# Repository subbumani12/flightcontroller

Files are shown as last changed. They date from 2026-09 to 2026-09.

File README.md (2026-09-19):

# Flight Controller

A custom **STM32F411-based flight controller PCB** designed for multirotor, UAV, robotics, and embedded flight-control applications.

The board integrates an IMU, magnetometer, barometric sensor, EEPROM, MicroSD storage, USB-C, SWD debugging, UART interfaces, and dedicated motor/auxiliary outputs on a compact **2-layer PCB** designed in KiCad.

## 3D Render
<p align="center">
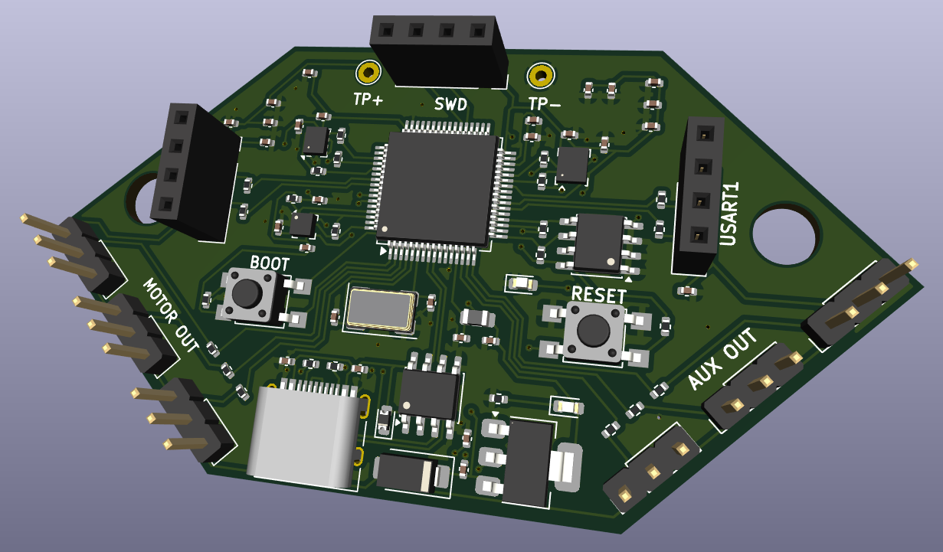
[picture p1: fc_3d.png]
STM32 Flight Controller 3D Render
  
</p>

---

## ✈️ Overview

This project is a custom flight-controller hardware design centered around the **STM32F411RET6 ARM Cortex-M4** microcontroller.

The STM32 handles sensor acquisition, flight-control processing, peripheral communication, data logging, and motor/auxiliary output generation.

The board combines:

* Inertial sensing
* Magnetic heading measurement
* Barometric altitude measurement
* Non-volatile configuration storage
* Flight-data logging
* USB communication
* SWD programming/debugging
* Motor and auxiliary outputs
* UART communication

The PCB was designed in **KiCad**, with emphasis on compact routing, sensor decoupling, accessible debugging, and organized external interfaces.

---

## 🔧 Hardware Features

| Component | Part |
| --- | --- |
| **Microcontroller** | STM32F411RET6 |
| **IMU** | LSM6DS3 – 3-axis Accelerometer + 3-axis Gyroscope |
| **Magnetometer** | LIS3MDL – 3-axis |
| **Barometer** | BMP280 |
| **EEPROM** | AT24C256A |
| **Storage** | MicroSD |
| **USB** | USB Type-C |
| **Debug** | SWD |
| **Serial** | UART1 / UART2 |
| **Motor Outputs** | MOTOR1 / MOTOR2 / MOTOR3 |
| **Auxiliary Outputs** | AUX1 / AUX2 / AUX3 |
| **Logic Supply** | 3.3 V |
| **PCB** | 2-layer |
| **EDA Tool** | KiCad |

The complete hardware feature set is documented in the original design specification.

---

## 🧠 System Architecture

```text
                         USB Type-C
                             │
                             ▼
                       USB Protection
                             │
                             ▼
                       Power / 3.3 V
                             │
                             ▼
                    ┌─────────────────┐
                    │   STM32F411     │
                    │   Flight MCU    │
                    └────────┬────────┘
                             │
          ┌──────────────────┼──────────────────┐
          │                  │                  │
          ▼                  ▼                  ▼
        I²C                 SPI               UART
          │                  │                  │
    ┌─────┼─────┐       ┌────┴────┐       ┌────┴────┐
    ▼     ▼     ▼       ▼         ▼       ▼         ▼
  LSM6DS3 LIS3MDL EEPROM BMP280   MicroSD  UART1    UART2
    │     │
    └─────┴────── Sensor Data
                    │
                    ▼
              STM32 Processing
                    │
             ┌──────┴──────┐
             ▼             ▼
        Motor Outputs   AUX Outputs
             │
             ▼
            ESCs
```

---

## 📡 Sensors & Peripherals

### LSM6DS3 IMU

The **LSM6DS3** provides:

* 3-axis accelerometer
* 3-axis gyroscope

It serves as the primary inertial sensor for attitude estimation, angular-rate measurement, motion detection, and flight-control feedback.

The IMU communicates with the STM32 through **I²C**.

### LIS3MDL Magnetometer

The **LIS3MDL** provides 3-axis magnetic-field measurements and can be used as a magnetic heading reference for navigation and orientation estimation.

It communicates through **I²C** and includes an interrupt connection to the MCU.

### BMP280 Barometer

The **BMP280** provides pressure measurements for:

* Relative altitude estimation
* Altitude-hold applications
* Vertical-motion estimation
* Flight-data logging

The sensor is connected through **SPI**.

### AT24C256A EEPROM

The onboard EEPROM provides non-volatile storage for:

* Configuration parameters
* Calibration data
* Controller settings
* Persistent system information

### MicroSD

A dedicated MicroSD interface provides onboard flight-data storage using SPI:

```text
SD_SPI_MOSI
SD_SPI_MISO
SD_SPI_SCK
SD_CHIPSEL
```

It can be used for sensor measurements, telemetry, debugging information, controller parameters, and flight logs.

---

## 🔌 Interfaces

### Motor Outputs

Three dedicated motor interfaces are provided:

```text
MOTOR1_OUT
MOTOR2_OUT
MOTOR3_OUT
```

Each connector provides:

```text
+5V
GND
SIGNAL
```

The motor-control signals are generated using STM32 timer peripherals and can interface with external ESCs or motor-control hardware.

### Auxiliary Outputs

```text
AUX1_OUT
AUX2_OUT
AUX3_OUT
```

Each provides:

```text
+5V
GND
SIGNAL
```

These can be used for additional actuators or flight-controller peripherals.

### UART

Two serial interfaces are exposed:

```text
UART1_TX
UART1_RX

UART2_TX
UART2_RX
```

Potential applications include GPS, telemetry, radio receivers, external sensors, and configuration interfaces.

### SWD

A dedicated SWD interface is provided for programming and debugging:

```text
SWDIO
SWCLK
3.3V
GND
```

The board also includes test points for convenient hardware debugging.

---

## ⚡ Power Architecture

The board uses an onboard **3.3 V regulation stage** for the STM32 and peripheral electronics.

The power section includes:

* Schottky diode protection
* AMS1117-3.3 regulator
* Input/output filtering capacitors
* Power indicator LED
* Ferrite filtering for the MCU supply

The additional ferrite filtering is intended to reduce high-frequency supply noise around the MCU.

---

## 🖥️ USB & Debugging

The board includes a **USB Type-C interface** providing:

* USB D+
* USB D−
* VBUS
* GND

USB ESD protection is included on the data interface.

The USB connection can be used for firmware development, communication, configuration, debugging, and powering the board during development.

Dedicated **BOOT** and **RESET** buttons are also provided for firmware programming, recovery, and MCU reset.

---

## 🧩 PCB Design

Designed using **KiCad**, the PCB focuses on compact two-layer implementation and practical hardware debugging.

### Design considerations

* Compact 2-layer PCB
* Dedicated ground routing/plane
* Local sensor decoupling
* Short high-speed peripheral connections
* Compact MCU placement
* Accessible SWD interface
* Dedicated motor and auxiliary connectors
* UART connectors
* USB Type-C
* Ferrite-filtered MCU supply
* Separated sensitive sensor circuitry
* Hardware test points
* Perimeter mounting holes

---

## 🔄 Flight-Control Data Flow

```text
        ┌─────────────┐
        │    IMU      │
        │   LSM6DS3   │
        └──────┬──────┘
               │
        ┌──────▼──────┐
        │ Magnetometer│
        │   LIS3MDL   │
        └──────┬──────┘
               │
        ┌──────▼──────┐
        │  Barometer  │
        │    BMP280   │
        └──────┬──────┘
               │
               ▼
        ┌──────────────┐
        │  STM32F411   │
        │    MCU       │
        └──────┬───────┘
               │
        ┌──────┼──────────┐
        ▼      ▼          ▼
     Motors   AUX     Telemetry
        │
        ▼
       ESCs
```

The STM32 acquires sensor data, processes the measurements using flight-control firmware, and generates outputs for connected ESCs, motors, and auxiliary peripherals.

---

## 🛠️ Tools & Technologies

* **KiCad** – Schematic & PCB design
* **STM32F411RET6** – ARM Cortex-M4 MCU
* **STM32 development tools / STM32CubeIDE**
* **I²C**
* **SPI**
* **USART**
* **USB**
* **SWD**

---

## 🚀 Potential Future Improvements

Possible future revisions include:

* Additional motor channels
* CAN / CAN-FD
* GPS connector
* Dedicated telemetry interface
* Battery voltage/current monitoring
* Buzzer interface
* Additional IMU / redundant sensors
* External compass connector
* Barometer isolation
* Improved power-input protection
* Dedicated receiver interface
* Additional test points
* Improved PCB signal integrity

---

## 🎯 Applications

This hardware platform can be explored for:

* Multirotor flight controllers
* UAV development
* Drone flight-control systems
* Autonomous aerial vehicles
* Embedded navigation
* Sensor-fusion experiments
* Flight-data logging
* Robotics
* Embedded control systems
* UAV hardware prototyping

---

## 📌 Project Status

**Hardware:** PCB design completed
**EDA:** KiCad
**Architecture:** STM32F411-based
**PCB:** 2-layer

This project is intended for **educational, research, and UAV hardware-development purposes**.

---

## 📄 License

This project is open-source and intended for educational, research, and UAV hardware-development purposes.

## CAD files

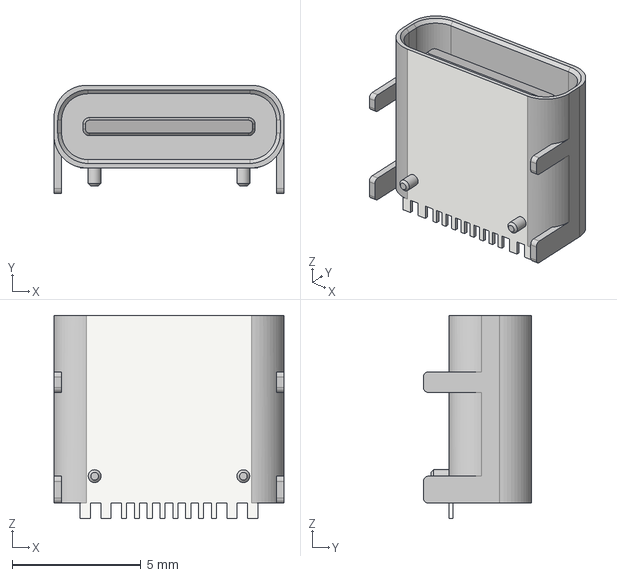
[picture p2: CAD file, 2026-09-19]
USB_C_Receptacle_HRO_TYPE-C-31-M-12.step
8.94 x 4.21 x 7.90 mm

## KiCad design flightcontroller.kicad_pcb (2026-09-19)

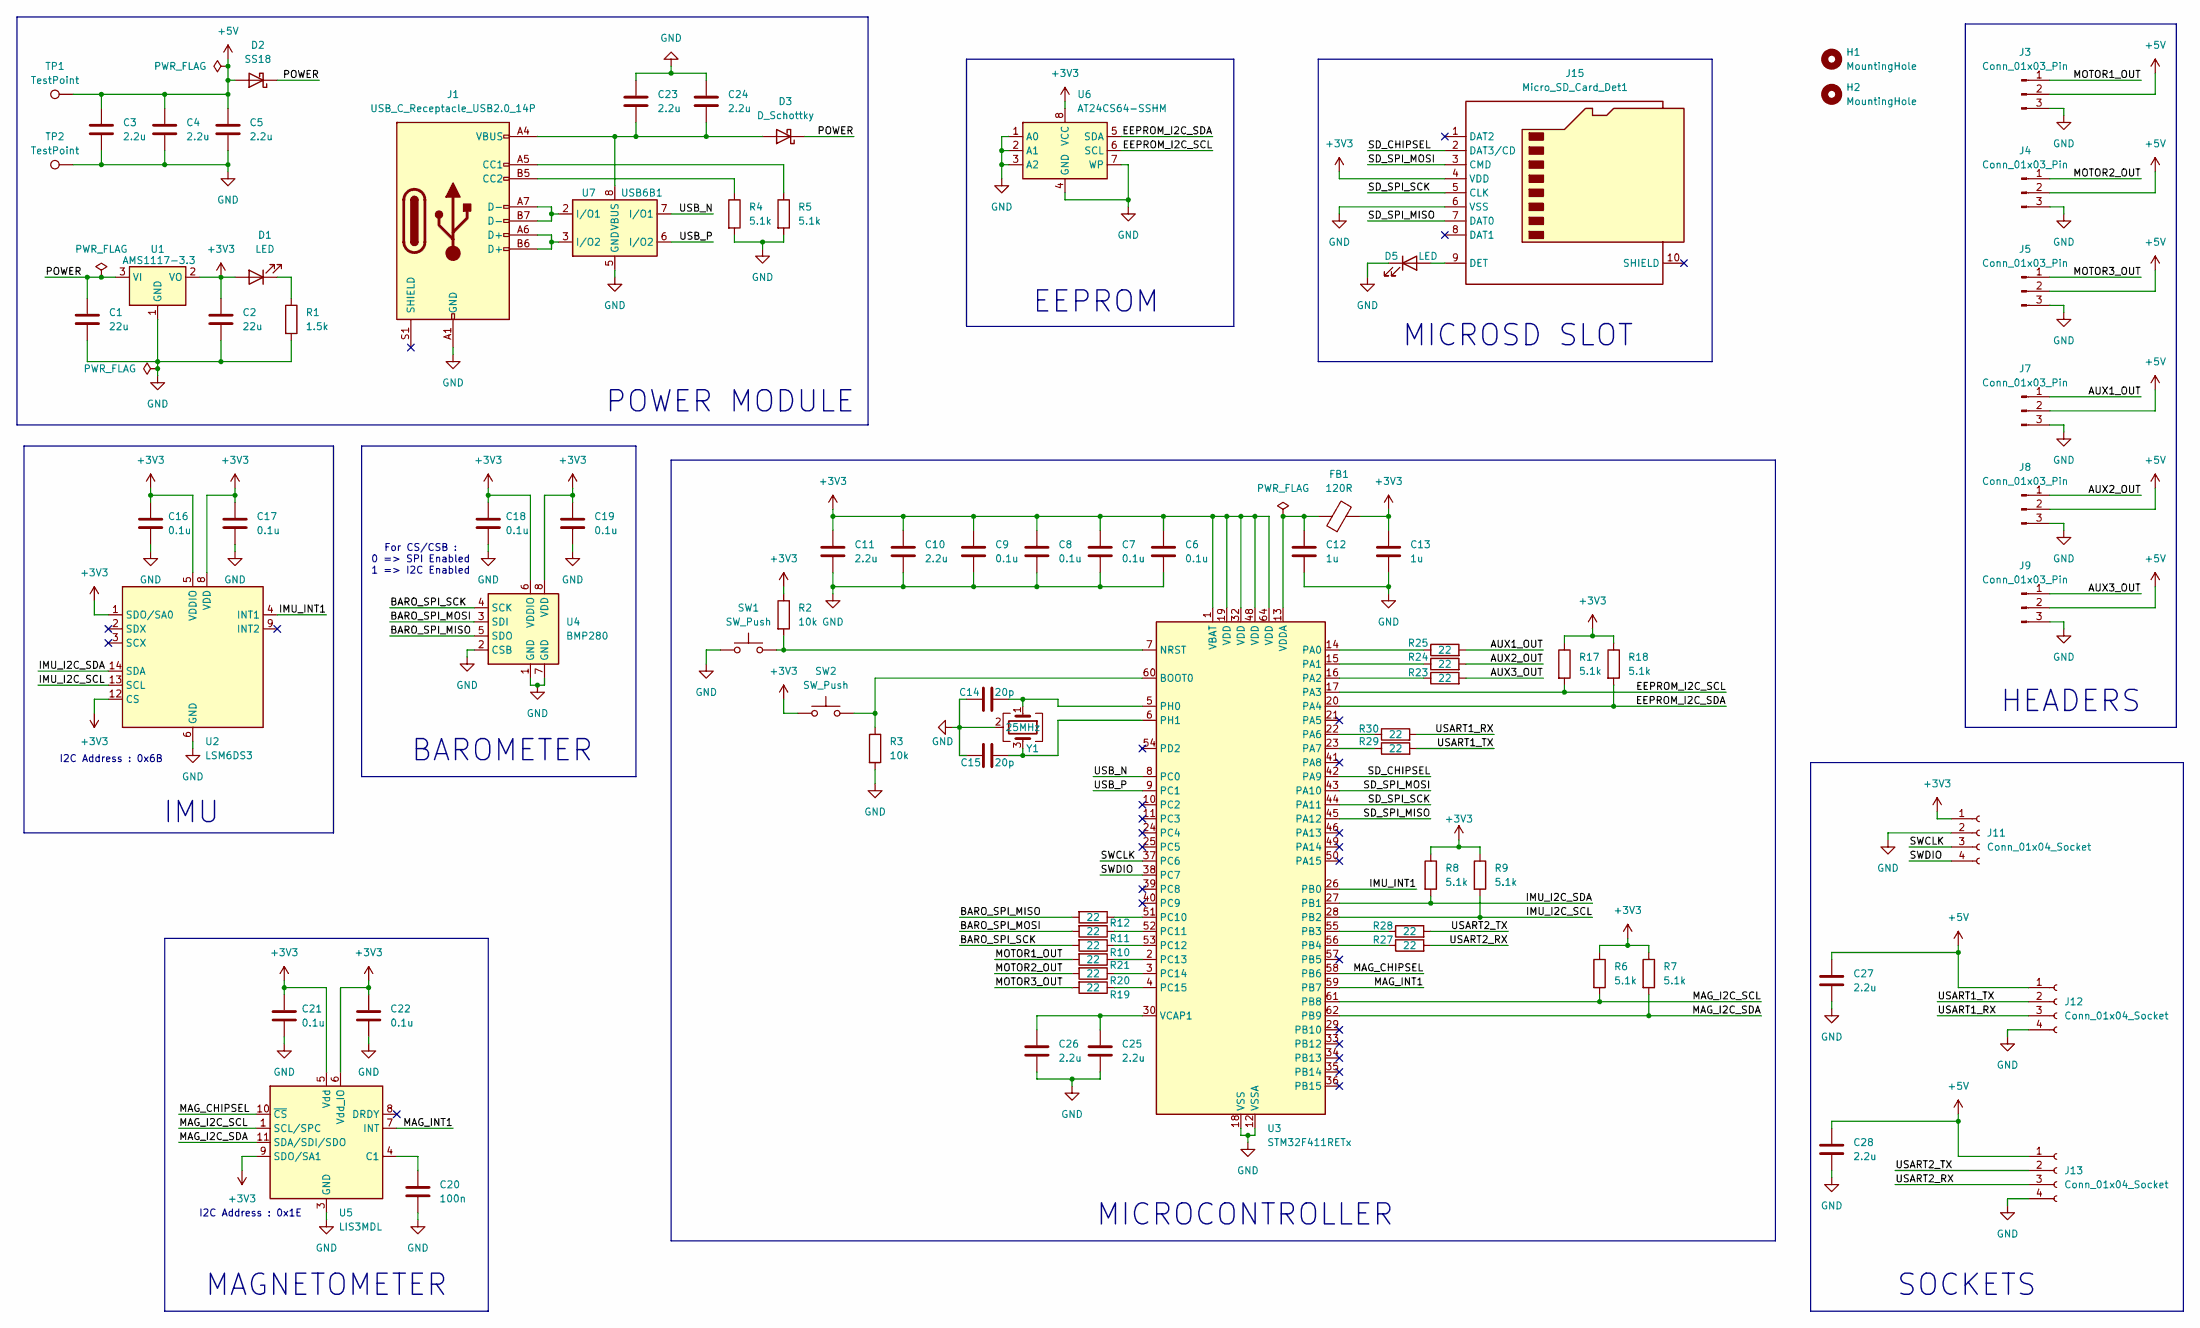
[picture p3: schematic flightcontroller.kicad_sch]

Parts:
C1, C2: 22u; C_0402_1005Metric
C3, C4, C5, C10, C11, C23, C24, C25, C26, C27, C28: 2.2u; C_0402_1005Metric
C6, C7, C8, C9, C16, C17, C18, C19, C21, C22: 0.1u; C_0402_1005Metric
C12, C13: 1u; C_0402_1005Metric
C14, C15: 20p; C_0402_1005Metric
C20: 100n; C_0402_1005Metric
D1, D5: LED; LED_0603_1608Metric
D2: SS18; D_SMA
D3: D_Schottky; D_0603_1608Metric
FB1: 120R; L_0805_2012Metric
H1, H2: MountingHole; MountingHole_5mm
J1: USB_C_Receptacle_USB2.0_14P; USB_C_Receptacle_HRO_TYPE-C-31-M-12
J3, J4, J5, J7, J8, J9: Conn_01x03_Pin; PinHeader_1x03_P2.54mm_Vertical
J11, J12, J13: Conn_01x04_Socket; PinSocket_1x04_P2.54mm_Vertical
J15: Micro_SD_Card_Det1; microSD_HC_Molex_104031-0811
R1: 1.5k; R_0402_1005Metric
R2, R3: 10k; R_0402_1005Metric
R4, R5, R6, R7, R8, R9, R17, R18: 5.1k; R_0402_1005Metric
R10, R11, R12, R19, R20, R21, R23, R24, R25, R27, R28, R29, R30: 22; R_0402_1005Metric
SW1, SW2: SW_Push; SW_SPST_TL3305A
TP1, TP2: TestPoint; TestPoint_THTPad_D2.0mm_Drill1.0mm
U1: AMS1117-3.3; SOT-223-3_TabPin2
U2: LSM6DS3; LGA-14_3x2.5mm_P0.5mm_LayoutBorder3x4y
U3: STM32F411RETx; LQFP-64_10x10mm_P0.5mm
U4: BMP280; Bosch_LGA-8_2x2.5mm_P0.65mm_ClockwisePinNumbering
U5: LIS3MDL; LGA-12_2x2mm_P0.5mm
U6: AT24CS64-SSHM; SOIC-8_3.9x4.9mm_P1.27mm
U7: USB6B1; SOIC-8_3.9x4.9mm_P1.27mm
Y1: 25MHz; Crystal_SMD_0603-4Pin_6.0x3.5mm

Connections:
+3V3: C2.1, C6.1, C7.1, C8.1, C9.1, C10.1, C11.1, C13.1, C16.1, C17.1, C18.1, C19.1, C21.1, C22.1, D1.2 (A), FB1.2, J11.1, J15.4 (VDD), R2.1, R6.1, R7.1, R8.1, R9.1, R17.1, R18.1, SW2.1, U1.2 (VO), U2.1 (SDO/SA0), U2.5 (VDDIO), U2.8 (VDD), U2.12 (CS), U3.1 (VBAT), U3.19 (VDD), U3.32 (VDD), U3.48 (VDD), U3.64 (VDD), U4.6 (VDDIO), U4.8 (VDD), U5.5 (Vdd), U5.6 (Vdd_IO), U5.9 (SDO/SA1), U6.8 (VCC)
+5V: C3.1, C4.1, C5.1, C27.1, C28.1, D2.2 (A), J3.2, J4.2, J5.2, J7.2, J8.2, J9.2, J12.1, J13.1, TP1.1
/AUX1_OUT: J7.1, R25.2
/AUX2_OUT: J8.1, R24.2
/AUX3_OUT: J9.1, R23.2
/BARO_SPI_MISO: R12.2, U4.5 (SDO)
/BARO_SPI_MOSI: R11.2, U4.3 (SDI)
/BARO_SPI_SCK: R10.2, U4.4 (SCK)
/EEPROM_I2C_SCL: R17.2, U3.17 (PA3), U6.6 (SCL)
/EEPROM_I2C_SDA: R18.2, U3.20 (PA4), U6.5 (SDA)
/IMU_I2C_SCL: R9.2, U2.13 (SCL), U3.28 (PB2)
/IMU_I2C_SDA: R8.2, U2.14 (SDA), U3.27 (PB1)
/IMU_INT1: U2.4 (INT1), U3.26 (PB0)
/MAG_CHIPSEL: U3.58 (PB6), U5.10 (~CS)
/MAG_I2C_SCL: R6.2, U3.61 (PB8), U5.1 (SCL/SPC)
/MAG_I2C_SDA: R7.2, U3.62 (PB9), U5.11 (SDA/SDI/SDO)
/MAG_INT1: U3.59 (PB7), U5.7 (INT)
/MOTOR1_OUT: J3.1, R21.2
/MOTOR2_OUT: J4.1, R20.2
/MOTOR3_OUT: J5.1, R19.2
/POWER: C1.1, D2.1 (K), D3.1 (K), U1.3 (VI)
/SD_CHIPSEL: J15.2 (DAT3/CD), U3.42 (PA9)
/SD_SPI_MISO: J15.7 (DAT0), U3.45 (PA12)
/SD_SPI_MOSI: J15.3 (CMD), U3.43 (PA10)
/SD_SPI_SCK: J15.5 (CLK), U3.44 (PA11)
/SWCLK: J11.3, U3.37 (PC6)
/SWDIO: J11.4, U3.38 (PC7)
/USART1_RX: J12.3, R30.2
/USART1_TX: J12.2, R29.2
/USART2_RX: J13.3, R27.2
/USART2_TX: J13.2, R28.2
/USB_N: U3.8 (PC0), U7.7 (I/O1)
/USB_P: U3.9 (PC1), U7.6 (I/O2)
GND: C1.2, C2.2, C3.2, C4.2, C5.2, C6.2, C7.2, C8.2, C9.2, C10.2, C11.2, C12.2, C13.2, C14.1, C15.2, C16.2, C17.2, C18.2, C19.2, C20.2, C21.2, C22.2, C23.1, C24.1, C25.2, C26.2, C27.2, C28.2, D5.1 (K), J1.A1 (GND), J1.A12 (GND), J1.B1 (GND), J1.B12 (GND), J3.3, J4.3, J5.3, J7.3, J8.3, J9.3, J11.2, J12.4, J13.4, J15.6 (VSS), R1.2, R3.2, R4.2, R5.2, SW1.1, TP2.1, U1.1 (GND), U2.6 (GND), U2.7 (GND), U3.12 (VSSA), U3.18 (VSS), U3.31 (VSS), U3.47 (VSS), U3.63 (VSS), U4.1 (GND), U4.2 (CSB), U4.7 (GND), U5.2 (GND), U5.3 (GND), U5.12 (GND), U6.1 (A0), U6.2 (A1), U6.3 (A2), U6.4 (GND), U6.7 (WP), U7.4 (GND), U7.5 (GND), Y1.2 (G), Y1.4 (G)
unnamed: D1.1 (K), R1.1
unnamed: C23.2, C24.2, D3.2 (A), J1.A4 (VBUS), J1.A9 (VBUS), J1.B4 (VBUS), J1.B9 (VBUS), U7.1 (VBUS), U7.8 (VBUS)
unnamed: D5.2 (A), J15.9 (DET)
unnamed: J1.A5 (CC1), R5.1
unnamed: J1.B5 (CC2), R4.1
unnamed: J1.A6 (D+), J1.B6 (D+), U7.3 (I/O2)
unnamed: J1.A7 (D-), J1.B7 (D-), U7.2 (I/O1)
unnamed: R3.1, SW2.2, U3.60 (BOOT0)
unnamed: R2.2, SW1.2, U3.7 (NRST)
unnamed: R25.1, U3.14 (PA0)
unnamed: R24.1, U3.15 (PA1)
unnamed: R23.1, U3.16 (PA2)
unnamed: R30.1, U3.22 (PA6)
unnamed: R29.1, U3.23 (PA7)
unnamed: R28.1, U3.55 (PB3)
unnamed: R27.1, U3.56 (PB4)
unnamed: R12.1, U3.51 (PC10)
unnamed: R11.1, U3.52 (PC11)
unnamed: R10.1, U3.53 (PC12)
unnamed: R21.1, U3.2 (PC13)
unnamed: R20.1, U3.3 (PC14)
unnamed: R19.1, U3.4 (PC15)
unnamed: C14.2, U3.5 (PH0), Y1.1
unnamed: C15.1, U3.6 (PH1), Y1.3
unnamed: C25.1, C26.1, U3.30 (VCAP1)
unnamed: C12.1, FB1.1, U3.13 (VDDA)
unnamed: C20.1, U5.4 (C1)

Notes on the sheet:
BAROMETER
For CS/CSB : 0 => SPI Enabled 1 => I2C Enabled
I2C Address : 0x1E
I2C Address : 0x6B
MICROSD SLOT
MICROCONTROLLER
IMU
SOCKETS
EEPROM
POWER MODULE
MAGNETOMETER
HEADERS

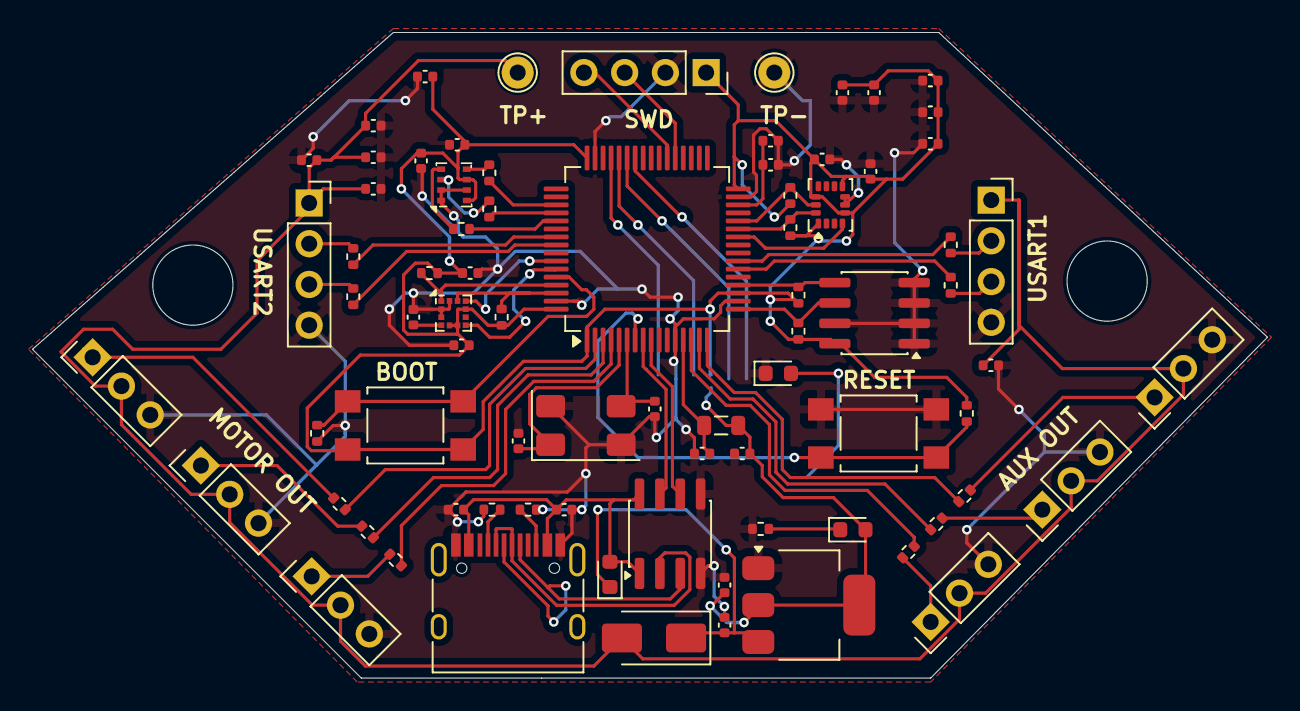
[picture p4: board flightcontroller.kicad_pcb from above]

Board: 2 copper layers, 77.0 x 40.2 mm, 82 parts (1 on the bottom side), 61 nets.
